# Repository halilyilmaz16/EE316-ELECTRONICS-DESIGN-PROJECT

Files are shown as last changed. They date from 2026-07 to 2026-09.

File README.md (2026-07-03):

# Capacitive Water Level Controller

An analog closed-loop water level control system designed and implemented
for the EE 316 Electronic Design Project at İzmir Institute of Technology.

The system detects liquid-level variations using a custom cylindrical
capacitive sensor. The sensor output is processed through phase detection,
filtering, amplification, error generation, and PWM stages. The resulting
PWM signal controls a submersible DC water pump through an L298N motor driver.

## Key Features

- Custom cylindrical capacitive water-level sensor
- TLC555-based oscillator
- XOR-based phase detection
- RC filtering and LM358 signal amplification
- Adjustable reference water level
- PWM-based pump speed control
- Motor overcurrent protection
- LTspice simulation and real-world circuit testing

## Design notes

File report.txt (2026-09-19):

Bilgi: İşlem sembolü 'C1:Capacitor_THT:C_Disc_D4.3mm_W1.9mm_P5.00mm'.
Bilgi: İşlem sembolü 'C2:Capacitor_THT:C_Disc_D5.0mm_W2.5mm_P5.00mm'.
Bilgi: İşlem sembolü 'C3:Capacitor_THT:CP_Radial_D5.0mm_P2.50mm'.
Bilgi: İşlem sembolü 'C4:Capacitor_THT:CP_Radial_D5.0mm_P2.50mm'.
Bilgi: İşlem sembolü 'C5:Capacitor_THT:CP_Radial_D5.0mm_P2.50mm'.
Bilgi: İşlem sembolü 'C6:Capacitor_THT:C_Disc_D4.3mm_W1.9mm_P5.00mm'.
Bilgi: İşlem sembolü 'C7:Capacitor_THT:C_Disc_D5.0mm_W2.5mm_P5.00mm'.
Bilgi: İşlem sembolü 'J1:Connector_PinSocket_2.54mm:PinSocket_1x02_P2.54mm_Vertical'.
Bilgi: İşlem sembolü 'J2:Connector_PinSocket_2.54mm:PinSocket_1x01_P2.54mm_Vertical'.
Bilgi: İşlem sembolü 'J3:Connector_PinSocket_2.54mm:PinSocket_1x02_P2.54mm_Vertical'.
Bilgi: İşlem sembolü 'R1:Resistor_THT:R_Axial_DIN0207_L6.3mm_D2.5mm_P7.62mm_Horizontal'.
Bilgi: İşlem sembolü 'R2:Resistor_THT:R_Axial_DIN0207_L6.3mm_D2.5mm_P7.62mm_Horizontal'.
Bilgi: İşlem sembolü 'R3:Resistor_THT:R_Axial_DIN0207_L6.3mm_D2.5mm_P7.62mm_Horizontal'.
Bilgi: İşlem sembolü 'R4:Resistor_THT:R_Axial_DIN0207_L6.3mm_D2.5mm_P7.62mm_Horizontal'.
Bilgi: İşlem sembolü 'R5:Resistor_THT:R_Axial_DIN0207_L6.3mm_D2.5mm_P7.62mm_Horizontal'.
Bilgi: İşlem sembolü 'R6:Resistor_THT:R_Axial_DIN0207_L6.3mm_D2.5mm_P7.62mm_Horizontal'.
Bilgi: İşlem sembolü 'R7:Resistor_THT:R_Axial_DIN0207_L6.3mm_D2.5mm_P7.62mm_Horizontal'.
Bilgi: İşlem sembolü 'R8:Resistor_THT:R_Axial_DIN0207_L6.3mm_D2.5mm_P7.62mm_Horizontal'.
Bilgi: İşlem sembolü 'R9:Resistor_THT:R_Axial_DIN0207_L6.3mm_D2.5mm_P7.62mm_Horizontal'.
Bilgi: İşlem sembolü 'R10:Resistor_THT:R_Axial_DIN0207_L6.3mm_D2.5mm_P7.62mm_Horizontal'.
Bilgi: İşlem sembolü 'R11:Resistor_THT:R_Axial_DIN0207_L6.3mm_D2.5mm_P7.62mm_Horizontal'.
Bilgi: İşlem sembolü 'R16:Resistor_THT:R_Axial_DIN0207_L6.3mm_D2.5mm_P7.62mm_Horizontal'.
Bilgi: İşlem sembolü 'R14:Resistor_THT:R_Axial_DIN0207_L6.3mm_D2.5mm_P7.62mm_Horizontal'.
Bilgi: İşlem sembolü 'R15:Resistor_THT:R_Axial_DIN0207_L6.3mm_D2.5mm_P7.62mm_Horizontal'.
Bilgi: İşlem sembolü 'R12:Resistor_THT:R_Axial_DIN0207_L6.3mm_D2.5mm_P7.62mm_Horizontal'.
Bilgi: İşlem sembolü 'R13:Resistor_THT:R_Axial_DIN0207_L6.3mm_D2.5mm_P7.62mm_Horizontal'.
Bilgi: İşlem sembolü 'RV1:Potentiometer_THT:Potentiometer_Piher_PC-16_Single_Vertical'.
Bilgi: İşlem sembolü 'U1:Package_DIP:DIP-8_W7.62mm'.
Bilgi: İşlem sembolü 'U2:Package_DIP:DIP-8_W7.62mm'.
Bilgi: İşlem sembolü 'U3:Package_DIP:DIP-14_W7.62mm'.
Bilgi: İşlem sembolü 'U4:Package_DIP:DIP-8_W7.62mm'.
Bilgi: İşlem sembolü 'U5:Package_DIP:DIP-14_W7.62mm'.
Bilgi: İşlem sembolü 'U6:Package_DIP:DIP-8_W7.62mm'.
R11 birim meta verileri güncellendi.
R11 iz düşümü 'Resistor_SMD:R_0603_1608Metric'den 'Resistor_THT:R_Axial_DIN0207_L6.3mm_D2.5mm_P7.62mm_Horizontal'e değiştirildi.
R11 alanı güncellendi.
Uyarı: U3 bileşeni 4 pedi için ağ bağlantısı bulunamadı (sembolde 4 pini yok).
Uyarı: U3 bileşeni 13 pedi için ağ bağlantısı bulunamadı (sembolde 13 pini yok).
Uyarı: U3 bileşeni 6 pedi için ağ bağlantısı bulunamadı (sembolde 6 pini yok).
Uyarı: U3 bileşeni 5 pedi için ağ bağlantısı bulunamadı (sembolde 5 pini yok).
Uyarı: U3 bileşeni 8 pedi için ağ bağlantısı bulunamadı (sembolde 8 pini yok).
Uyarı: U3 bileşeni 11 pedi için ağ bağlantısı bulunamadı (sembolde 11 pini yok).
Uyarı: U3 bileşeni 9 pedi için ağ bağlantısı bulunamadı (sembolde 9 pini yok).
Uyarı: U3 bileşeni 10 pedi için ağ bağlantısı bulunamadı (sembolde 10 pini yok).
Uyarı: U2 bileşeni 8 pedi için ağ bağlantısı bulunamadı (sembolde 8 pini yok).
Uyarı: U4 bileşeni 6 pedi için ağ bağlantısı bulunamadı (sembolde 6 pini yok).
Uyarı: U4 bileşeni 4 pedi için ağ bağlantısı bulunamadı (sembolde 4 pini yok).
Uyarı: U4 bileşeni 5 pedi için ağ bağlantısı bulunamadı (sembolde 5 pini yok).
Uyarı: U4 bileşeni 7 pedi için ağ bağlantısı bulunamadı (sembolde 7 pini yok).
Uyarı: U4 bileşeni 8 pedi için ağ bağlantısı bulunamadı (sembolde 8 pini yok).
Uyarı: U2 bileşeni 4 pedi için ağ bağlantısı bulunamadı (sembolde 4 pini yok).
Uyarı: U3 bileşeni 12 pedi için ağ bağlantısı bulunamadı (sembolde 12 pini yok).
Uyarı: U6 bileşeni 4 pedi için ağ bağlantısı bulunamadı (sembolde 4 pini yok).
Uyarı: U6 bileşeni 8 pedi için ağ bağlantısı bulunamadı (sembolde 8 pini yok).
Uyarı: U6 bileşeni 7 pedi için ağ bağlantısı bulunamadı (sembolde 7 pini yok).
Uyarı: U6 bileşeni 6 pedi için ağ bağlantısı bulunamadı (sembolde 6 pini yok).
Uyarı: U6 bileşeni 5 pedi için ağ bağlantısı bulunamadı (sembolde 5 pini yok).

Bilgi: Toplam uyarı: 21, hata: 0.

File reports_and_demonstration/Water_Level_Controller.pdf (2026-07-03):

## WATER LEVEL CONTROLLER

Electronic Design Project I

Hasan Veysel Tutar | Halil Yılmaz | Doruk Oğüt ¨

Department of Electrical and Electronics Engineering Izmir Institute of Technology

June 2026

Tutar, Yılmaz, Oğüt (IYTE) ¨ | Water Level Controller | June 2026 | 1 / 11

## Project Objective

Goal: Design an analog closed-loop system.

Maintain precise fluid levels inside the tank.

Prevent tank overflow and protect the pump from dry-run conditions.

Tutar, Yılmaz, Oğüt (IYTE) ¨ | Water Level Controller | June 2026 | 2 / 11

## Capacitive Probe Design

Cylindrical Capacitive Probe

Design Targets:

Target | Min. | Max. | Unit
Water level at capacitor | 5 | 15 | cm
Capacitance | 213 | 661 | pF

Governing Formula:

C =

2πϵ0
ln(b/a)

[Kw L1 + KaL2]

Kw ≈ 80 (Water)
Ka ≈ 1 (Air)

Result: Linear capacitance change relative to water height.

Tutar, Yılmaz, Oğüt (IYTE) ¨ | Water Level Controller | June 2026 | 3 / 11

## Clock Signal Generation

NE555 Timer
Configured in astable mode. Generates a continuous, stable square wave reference signal.

Design Formula:

f =

1.44
(RA + 2RB )C

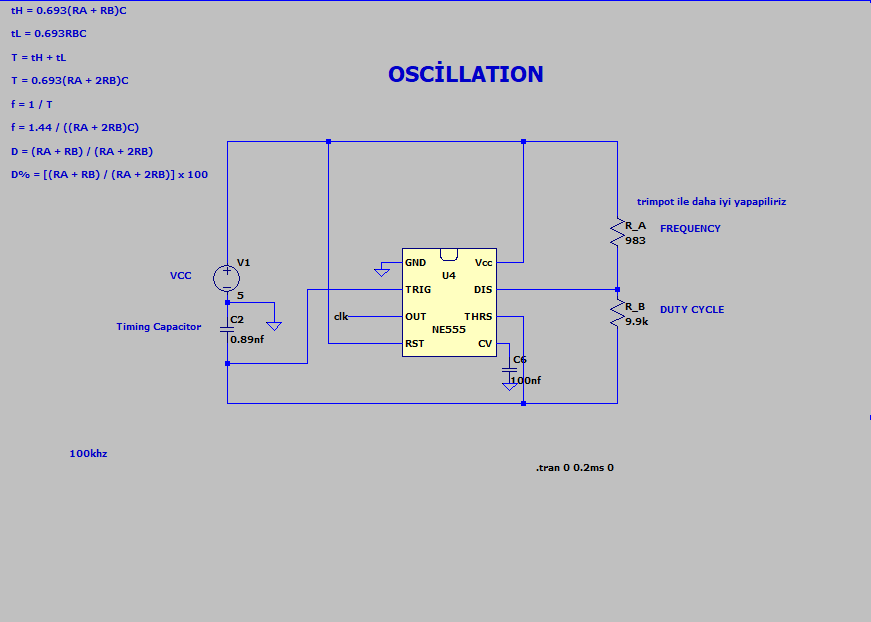
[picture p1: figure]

Figure: Clock Signal Generation Circuit

Tutar, Yılmaz, Oğüt (IYTE) ¨ | Water Level Controller | June 2026 | 4 / 11

## Phase Comparator & LP Filter

Phase Shift & XOR Output

74LS86 XOR: Compares the Reference Clock with the Phase-Shifted Signal from the capacitor. Pulse width is directly proportional to phase difference.

RC LP Filter: Converts the high-frequency switching PWM components into a stable DC voltage representing the water level.

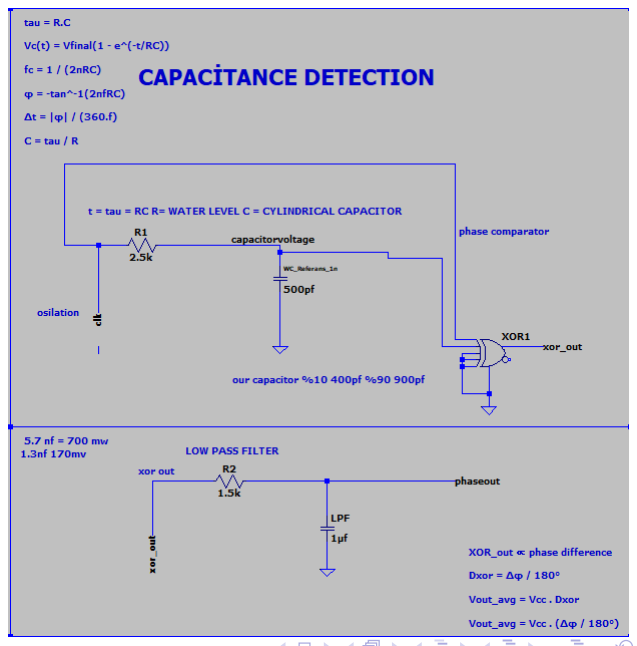
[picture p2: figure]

Figure: Phase Comparator Circuit Tutar, Yılmaz, Oğüt (IYTE) ¨ | Water Level Controller | June 2026 | 5 / 11

## Offset Amplifier

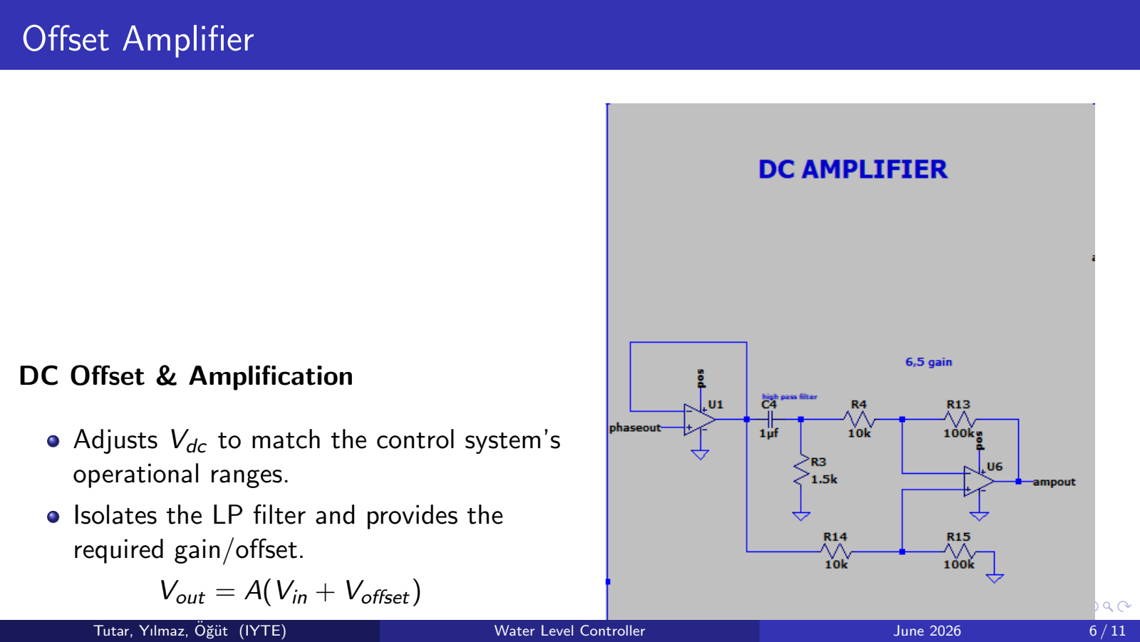
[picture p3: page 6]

DC Offset & Amplification

Adjusts Vdc to match the control system’s operational ranges.
Isolates the LP filter and provides the
required gain/offset.

Vout = A(Vin + Voffset)

Tutar, Yılmaz, Oğüt (IYTE) ¨ | Water Level Controller | June 2026 | 6 / 11

## Error Amplifier

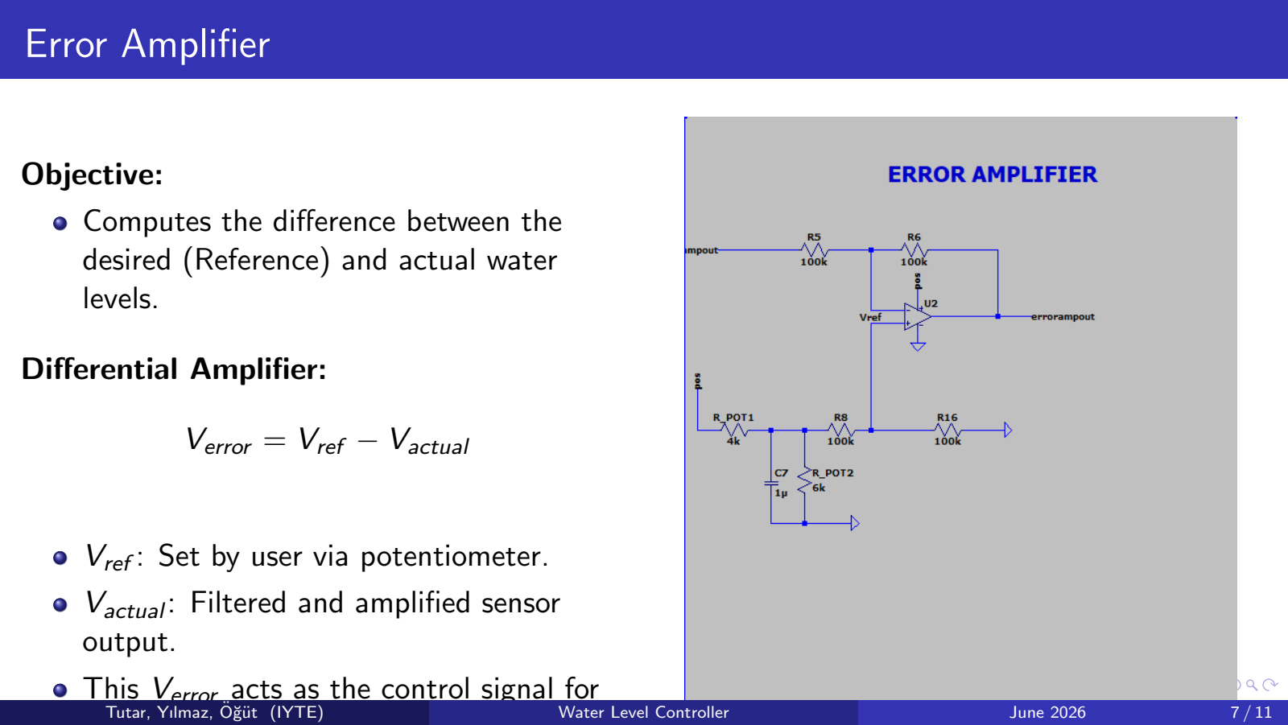
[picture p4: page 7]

Objective:

Computes the difference between the desired (Reference) and actual water levels.

Differential Amplifier:

Verror = Vref − Vactual

Vref : Set by user via potentiometer.

Vactual: Filtered and amplified sensor output.
This Verror acts as the control signal for
the PWM generation.
Tutar, Yılmaz, Oğüt (IYTE) ¨ | Water Level Controller | June 2026 | 7 / 11

## Reference Signal: Square & Triangular Wave

### 1. Square Wave Generator:

Created using 74LS74 D-type flip-flops.

Provides the base switching frequency

(fout = fclk /4).

### 2. Triangular Wave Generator:

RC filter network integrates the square
wave to produce a linear triangular carrier

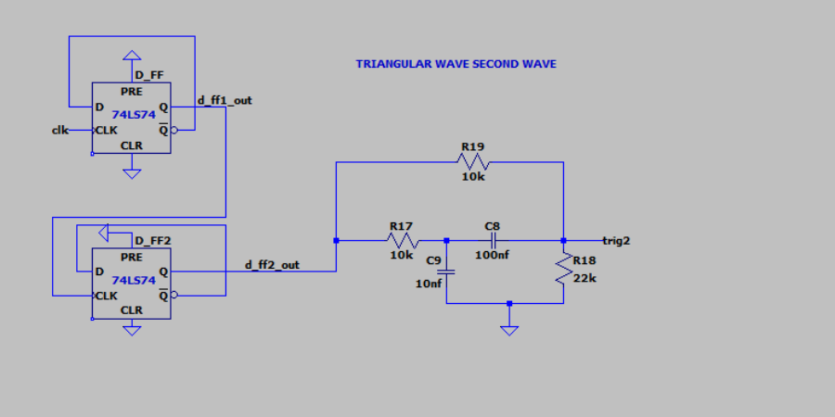
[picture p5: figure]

wave (Vtri). | Figure: Triangular Wave Generator
Tutar, Yılmaz, Oğüt (IYTE) ¨ | Water Level Controller | June 2026 | 8 / 11

## PWM Generator

Operation Principle:

Compares Verror and Vtri.

Logic:

If Verror > Vtri → HIGH

If Verror < Vtri → LOW

Result:
Duty cycle ∝ error.
High error (low water) = Fast pump speed.

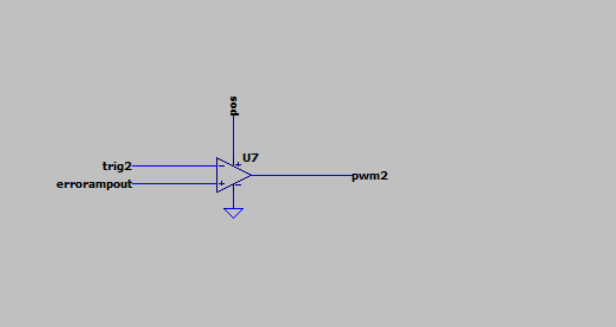
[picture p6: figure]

Figure: PWM Generator Circuit

Tutar, Yılmaz, Oğüt (IYTE) ¨ | Water Level Controller | June 2026 | 9 / 11

## Motor Driver Integration

L298N H-Bridge Driver

Drives the DC water pump using the generated PWM signal.
High-current capability suitable for inductive loads (up to 2A per channel).

Efficient power switching based on Duty Cycle, accurately controlling the pump flow rate.

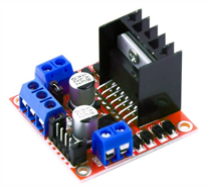
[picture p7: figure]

Figure: L298N Motor Driver Module

Tutar, Yılmaz, Oğüt (IYTE) ¨ | Water Level Controller | June 2026 | 10 / 11

# Thank You for Your Attention

EE 316 - Electronic Design Project I

Tutar, Yılmaz, Oğüt (IYTE) ¨ | Water Level Controller | June 2026 | 11 / 11

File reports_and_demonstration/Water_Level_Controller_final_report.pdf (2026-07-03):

İYTE - Department of Electrical and Electronics Engineering

EE 316 - Electronic Design Project, Sample Project Final Report | 1

## EE 316 - Electronic Design Project

## Project: P1

# Water Level Controller

## Final Project Report 25 June 2026

## Objective

To reduce water wastage and eliminate the need for human intervention when pumping water into tanks, it is important to design a simple control system that monitors water levels. This article presents the design and implementation of an automatic water level controller with a digital display. The circuit is low cost, easy to maintain, and operates on a replaceable battery. Our goal is to provide an efficient and effective solution for water level control in tanks using a simple circuit. Whether you are dealing with a domestic water tank or an industrial installation, a water level controller can make your life easier.

## Group Members

Common efforts:
Hasan Veysel Tutar: Capacitor design and manufacturing, real life circuit assembly and testing, and troubleshooting.
Halil Yılmaz: Simulations and circuit building assistance.
Doruk Öğüt: Simulations and circuit building assistance.

EE 316 - Electronic Design Project, Sample Project Final Report | 2

## Revision History

Week-5 (23.03.2026): We decided what to make the capacitor from.

Week-6 (30.03.2026): We tested our capacitor with the Signal Generator. We progressed as far as the DC signal section.

Week-7 (06.04.2026): We discussed how we could solve our oscillation problem with ICs. We decided on NE555 as the solution.

Week-8 (13.04.2026): We tested our Oscillation Circuit NE555 with electronic lab equipment [1].

Week-9 (20.04.2026): We tried to make progress by combining our oscillation circuit with a capacitor detection section.

Week-10 (27.04.2026): We have decided what we will use as an operational amplifier [6].

Week-11 (04.05.2026): According to our test results, the LM741 integrated circuit did not yield the same results as our simulations.

Week-12 (11.05.2026): Our datasheet research revealed that the LM358 integrated circuit is suitable for the remaining part of our circuit (Amplifier, PWM) [2].

Week-13 (18.05.2026): In the triangular wave section, we obtained a triangular wave by taking the main oscillation circuit, reducing its frequency to a quarter of its original value, and using filtering to account for possible offsets.

Week-14 (25.05.2026): Holiday week, The capacitor was broken, so we redesigned it.

Week-15 (01.06.2026): We completed all our circuits. We conducted troubleshooting for possible offsets.

Week-16 (08.06.2026): We completed all our circuits in the simulation. All the materials have been ordered.

Week-17 (15.06.2026): A demo video was filmed. A band member poured water on the circuit.

Week-18 (22.06.2026): Circuit Completed.

EE 316 - Electronic Design Project, Sample Project Final Report | 3

## 1.Introduction

The aim of this project is to develop an automated water level control system that uses capacitive sensing and feedback systems to reliably and effectively control water levels. The water level control system is designed to determine and manage the water level in a tank using capacitive sensors. When the water level drops below a certain level by the controller, the pump is triggered. When the water level rises above a certain limit, the pump shuts off.

Capacitive sensors, signal processing circuits, and a driver module used to operate a PWM-controlled motor are the system's core components. The dielectric properties of water allow the sensor to detect changes in water level. Resistors and capacitors, including logic gates and analog filters, pass the output from the sensors through various stages.

Another essential part of the system is a feedback loop controlled by an error amplifier. In this loop, the water level and the reference value are continuously compared. The amplifier adjusts control indicators that amplify any discrepancies between the reference value and the water level, thus maintaining the water at the correct level within the system [6].

The output of the error amplifier is used to generate the PWM signal [7]. The capacitive sensor detects the water levels, and the duty cycle of the PWM signal changes the motor operation. When the water level in the tank is below the desired level or completely empty, the motor operates at its maximum duty cycle [10]. As the water level in the tank rises, the duty cycle decreases and the motor switches off. The system also ensures smooth operation of the motor with a current-protected motor driver circuit.

We must overcome three major design challenges by making a water level controller:

Custom Capacitive Sensor Fabrication: Precise level detection necessitates exceptional geometric accuracy. To reduce expenses and prevent measurement inaccuracies associated with the "kettle effect," we utilized SolidWorks and 3D printing to fabricate tailored frames [9]. A continuous, single component aluminum surface was employed to enhance sensitivity, while premium electrical tape acted as a dielectric barrier to inhibit leakage currents and thermal fluctuations.

Signal Conversion through Oscillation: It is necessary to transform the sensor's changing capacitance into a digital signal. Capacitance variations are converted into a frequency modulated square wave using an astable mode NE555 timer [1]. The difficulty is choosing exact R1 and R2 values to retain high resolution while keeping the output frequency within the microcontroller's

Parasitic Voltage Leakage: A 500 mV leakage was detected at the XOR output during measurement, causing noise and reducing signal reliability. This became one of the project’s challenges and required improved grounding, insulation, and filtering.

EE 316 - Electronic Design Project, Sample Project Final Report | 4

## 1.1. Capacitive Water Level Sensors

Our system employs cylindrical capacitive sensors to detect variations in capacitance between two aluminum strips and a plastic tube situated within a tank filled with water. Fluctuations in the water level led the sensors to register changes in capacitance between the electrodes. The higher dielectric constant of water in comparison to air results in an increase in capacitance as the water level rises. We assessed and calculated the capacitance of the capacitor in air and observed how it varied at different water levels. Preliminary experiments indicated that the presence of water on the aluminum surface influenced the conductivity of the capacitor plates. Consequently, we applied a thin layer of plastic wrapping around the capacitive sensors to enhance their sensitivity. This adjustment enabled us to effectively track water levels. We employed the NE555 timer integrated circuit to produce a clock signal with the specified frequency and duty cycle values within the 0 − 5V range.

## 1.2. Signal Conditioning and DC Conversion

The capacitor's output was converted to direct current (DC) to enable the DC motor to operate effectively [5]. Our clock signal was subsequently used to feed the circuit after it was constructed, functioning as a phase comparison device. The circuit measured the phase difference between our clock signal and the capacitor output, generating a corresponding signal. This was achieved using a comparator comprising two XOR gates; the first digitized our system, while the second compared the capacitor output with the clock signal. The comparator's output was then passed through a low pass filter to produce a DC voltage signal. Prior to utilization, it was necessary to amplify the DC output, as the signal amplitude was initially too low, which risked amplification errors [8].

## 1.3. Error Amplification

We see that the error amplifier is a circuit that compares the difference between the reference water level and the actual water level. This acts as a feedback loop and keeps the system within its most effective range. When there is a difference between the reference level and the actual level, it continuously monitors and amplifies this difference through the error amplifier [7]. Initially, in the simulation, the supply voltages for the amplifier were set to 5V and GND, and Vrefwas varied between 0V and 4V. (Note that the maximum amplified DC signal level is 4V. In the experimental setup, a potentiometer is used to adjust the reference voltage. The water level in the bottle is divided into intervals, and the adjustment of the DC signal voltage values is matched to this interval. In this arrangement, the potentiometer sets a reference level voltage, and when the target water level is reached, the error amplifier compares this reference voltage to an actual voltage signal indicating how much water is in the container. Therefore, the motors only pump water when the water level is below the maximum level [6].

EE 316 - Electronic Design Project, Sample Project Final Report | 5

## 1.4 PWM Generation

The square wave generated by the NE555 timer first passes through an RC filter circuit to create a delayed version of the original signal. This delayed signal is then converted into a digital signal by using a ground reference XOR gate. After that, another XOR gate compares the original NE555 timer output with the digitized delayed signal. As a result of this comparison, a difference signal is produced at a very small millivolt level. Since this signal is too weak for direct use, it is amplified by a non inverting amplifier stage [6]. After amplification, the signal is applied to a differential amplifier, also called an error amplifier, together with a previously adjusted reference voltage to generate an error signal [7]. This error signal is then sent to the PWM generation stage, where it is compared with a triangular waveform to produce the PWM output. The duty cycle of the PWM signal changes continuously according to the water level, which allows accurate control of both the motor speed and the water flow [10].

## 1.5 Motor Driver Integration and Protection Circuit

Using PWM to drive the motor via L298 motor driver IC [4]. This integrated circuits design means it can switch effectively and operate safely with the DC motor [5]. The motor speed is directly controlled by the PWM duty cycle, which can be accurately regulated for water pump operation. The system can autorotate motor speed changes and keep water balance by changing the duty cycle according to the water level. This method made the operational safety and functionality of the motor even better.

## 1.6 Motor and Pump Control

The submersible pump can connect to a motor that runs based on the PWM controlled signal [10]. When the water comes to a maximum, the system reduces duties which slow down or stop pump action. The duty cycle increases when the water level drops below the minimum value, and pump runs to fill up the tank. Also, the present protection circuit is integrated to safeguard likely damage from carrying out such postures through the mode of motor overcurrent circumstances. Move on with the project, at this stage these circuit parts will be implemented over to a breadboard and at each stage signal integrity will be checked and finally check the full system operation under various water level conditions.

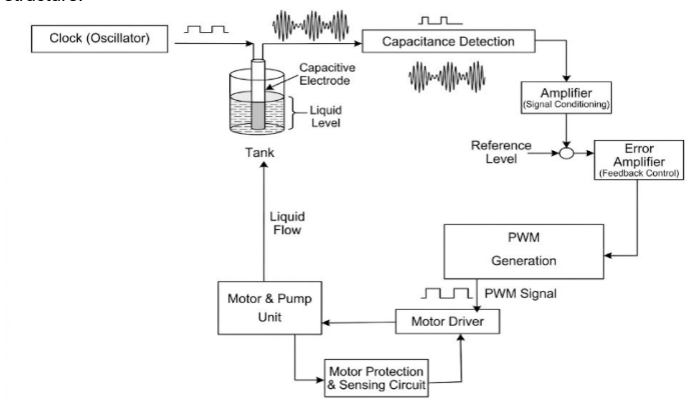
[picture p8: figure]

EE 316 - Electronic Design Project, Sample Project Final Report | 6

## 2. Technical Description

In order to accurately and continuously monitor the liquid level in the tank, we built this system with a closed-loop control structure. In our design, we sensed the liquid level by placing a capacitive electrode inside the tank. We were able to measure the capacitance change that happens when the liquid level varies by applying a high frequency signal produced by an oscillator from a constant DC source to this electrode. We converted this change obtained in the capacitive sensing block into an electrical signal and then processed it in the amplifier stage to bring it to a suitable level for control. We then compared this signal with a defined reference level in the error amplifier block to obtain the instantaneous error information of the system [7]. By transferring the generated error signal to the PWM generation block, we aimed to create the control signal to be used in the next stage of the system. The next goal of our design is to apply the generated PWM signal to a motor driver circuit to control the pump motor and thus automatically maintain the liquid level in the tank at the desired value. Accordingly, the motor driver, pump, and protection circuit blocks are planned for the later development stages of the system. With this approach, our primary goal is to establish the sensing and control infrastructure, and in the next stage, to transform the system into a fully closed-loop liquid level control structure.

Figure 1. Block Diagram of the Water Level Control System
The system begins by using a clock to create a square wave, which is subsequently transmitted to a capacitor's electrode. In the capacitance detecting part, we also want to produce a DC signal, which requires several intricate procedures.

First, we used a NE555 timer in astable mode to transform the steady DC supply voltage into a steady clock signal [1]. The handcrafted capacitive sensor, whose output changes with capacitance, was then subjected to this clock signal. A phase comparator was used to compare the reference clock and sensor output, and the resulting signal was transformed into PWM for the subsequent motor control stage.

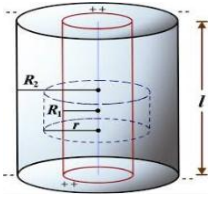
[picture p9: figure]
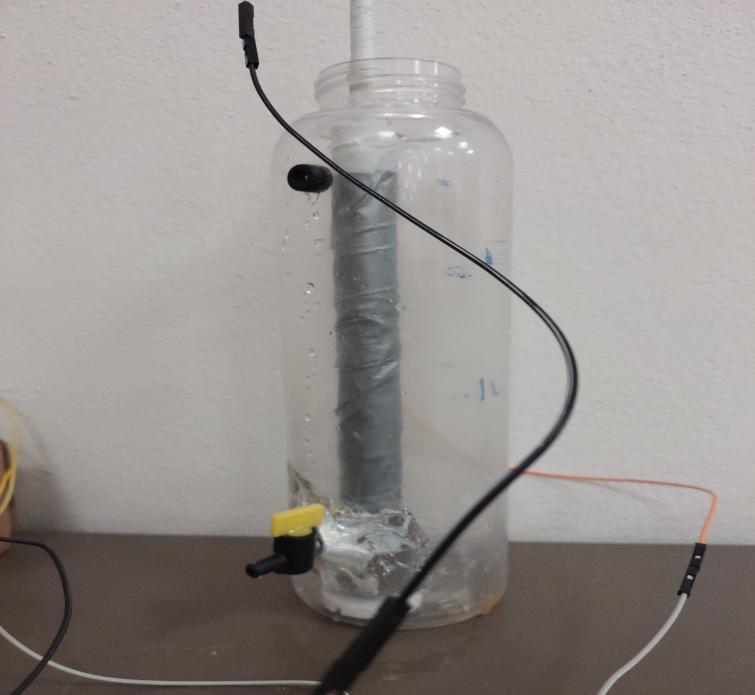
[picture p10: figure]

EE 316 - Electronic Design Project, Sample Project Final Report | 7

## 2.1. Capacitor Design

When designing our capacitor, we experimented with a variety of methods. In the end, we decided to create it using a 3D printer. The height and outside diameter of our capacitor were measured theoretically and determined to be 25 cm and 24.8 mm, respectively.

It was found that the cylinder within the capacitor was 28 cm tall. Additionally, the capacitor's inner and outer shell radii were found to be 4.2 mm and 9 cm, respectively, as seen in Figure 2 below.

Figure 2. Diagram of cylindrical capacitor

The capacitive sensor was built using aluminum tape on the external surfaces of the inner and outer cylindrical shells that formed the electrode structure of the sensor. This arrangement provides a measurable capacitance between the two conductive layers that varies according to the surrounding dielectric medium and enables liquid level detection as shown in Figure 3 below.

Figure 3.Picture of the Capacitor

EE 316 - Electronic Design Project, Sample Project Final Report | 8

According to our research, the formula for the capacitance of a cylindrical capacitor is given

(1)

C is the capacitance of the cylinder, a is the inner radius of the cylinder, L is
the length of the cylinder, b is the outer radius of the cylinder, | is the permittivity of
free space, and | is the permittivity of medium.
= | (2)
= | (3)

Then the total capacitance is:

| (4)
= | (5)

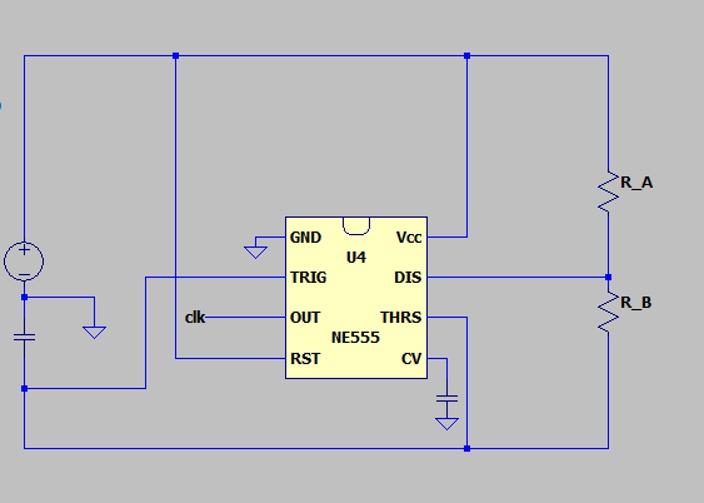
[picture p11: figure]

EE 316 - Electronic Design Project, Sample Project Final Report | 9

## 2.2 Oscillation Generation

Based on our preliminary research and design requirements, we selected the TLC555 timer to generate the excitation signal for the sensing stage. Due to its simple implementation, stable operation, and ability to produce a continuous square wave without external triggering, the TLC555 was chosen as the oscillator source [1]. Configured in astable mode, it generates a stable periodic signal that is used as the reference excitation input for the capacitive sensing circuit .

TLC 555 Astable Multivibrator

The TLC555 astable multivibrator circuit shown in Figure 4 generates a clock
signal, | ,which is a 35 kHz square wave oscillating between | and | ,
with approximately a | duty cycle. This clock signal provides a stable timing
reference essential for DC signal generation in our design [1].

Figure 4.TLC555 astable oscillator generates the reference square-wave signal

The Frequency is calculated with this formula:

(6)
And the duty cycle is calculated with:

(7)

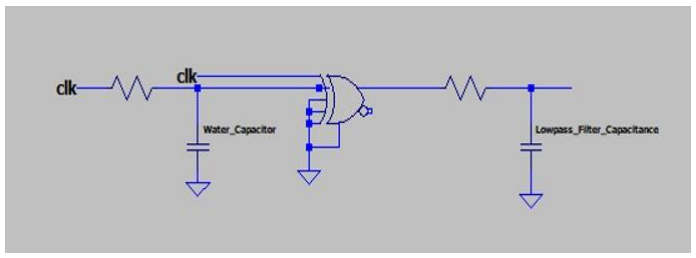
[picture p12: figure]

EE 316 - Electronic Design Project, Sample Project Final Report | 10

## 2.3 Capacitance Detection

At this point, we employed a straightforward RC network to monitor the charge discharge behavior of our capacitive sensor using the produced square wave signal. Based on the capacitor's charging and discharging properties, a phase-shifted waveform was produced when it reacted to the excitation signal. In order to stabilize the waveform and retrieve its phase-dependent behavior, this signal was then processed utilizing XOR-based phase comparison stages.

Figure 5.Circuit Diagram of Capacitance Detection
Delayed Signal Generation

Based on our preliminary research, we found that the simplest way to observe the capacitance variation of our handmade sensor was to examine its charge discharge behavior in a basic structure. By applying the generated square wave signal to the sensor, we obtained a delayed output due to the capacitor’s charging and discharging response. This phase shifted waveform allowed us to observe the capacitance effect directly in the time domain

The delay is determined by the time constant,

and the delayed output is described by

Signal Digitalization and Convert DC

Based on our analysis, the delayed analog signal needed to be converted into a more stable and measurable form for evaluation. To achieve this, we compared the delayed capacitor response with the reference clock signal using XOR-based phase comparison. Since the XOR gate (74LS86) produces HIGH output only when its inputs differ, the phase difference between the delayed signal and the reference signal was translated into a pulse-width-varying digital waveform [2].

The digital output was processed to obtain a stable, DC equivalent signal proportional to the detected phase shift. By converting the phase-dependent waveform into a DC level, a more stable representation of the capacitance variation was achieved. This enabled the sensor response to be observed as a measurable voltage level, thereby simplifying the evaluation of capacitance dependent behavior.

EE 316 - Electronic Design Project, Sample Project Final Report | 11

Filtering

After the XOR stage, the output signal contains high-frequency switching components and must be filtered to obtain a stable DC level. For this purpose, an low-pass filter is used to suppress the high-frequency ripple while preserving the average value of the signal. This allows the phase-dependent digital waveform to be converted into a smoother and more stable DC output.

The cutoff frequency of the filter is determined by:
=

This relation was used to select the filter parameters and evaluate the response of the filtering stage.

Capacitance Detector Design Targets
Description of design target | Min. | Max. | Unit
Delayed signal output voltage | 0 | 4.96
DC signal output voltage | 0 | 578
Filtering Frequency | 10 | 23
Capacitance Value | 1.5 | 5.15

Table 1. Capacitance Detection Design

## 2.4 Amplifier

Following the theory learned from the principles of analog amplifiers in Circuit Analysis I, an operational amplifier was employed to boost the voltage output after filtration.

A high pass filter was designed to limit any noise in low frequencies prior to amplifying the input signal.

Because the output voltage from the capacitance detection stage was too low for comparison purposes, a non-inverting amplifier was chosen to boost the output signal voltage while keeping its polarity intact.

The output voltage is expressed by the equation below:

Using the resistor values chosen above, the gain was controlled to achieve the desired output voltage. The circuit design is depicted in Figure 6. The output voltages are provided in the table below.

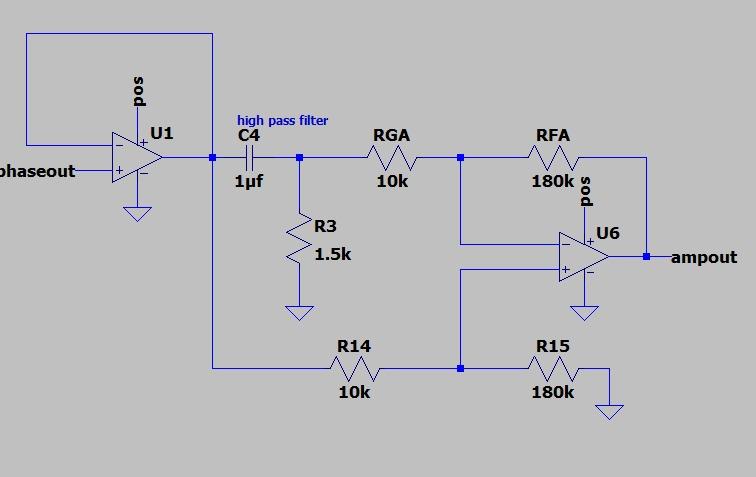
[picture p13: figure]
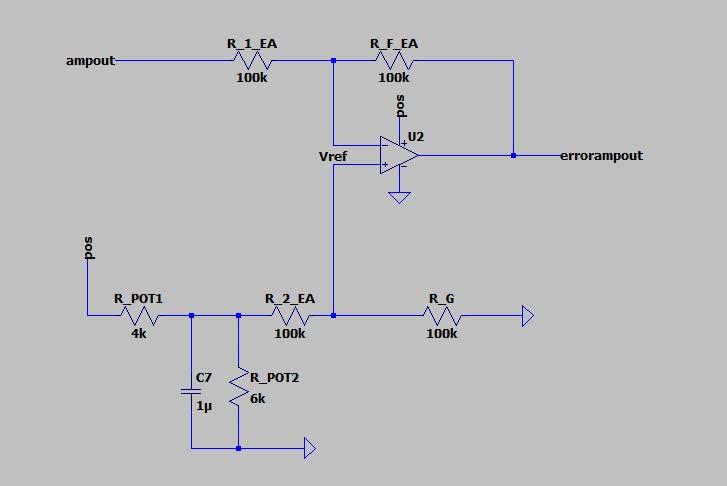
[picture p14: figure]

EE 316 - Electronic Design Project, Sample Project Final Report | 12

Figure 6.Circuit diagram of Amplifier
Amplifier Design Targets
Description of design target | Min. | Max. | Unit.
DC Voltage | 170 | 700 | mV
Output voltage for non-inverting amplifier | 3 | 4.2
Gain | 7.2 | 56.44 | -

Table 2. Amplifier design targets and parameters

## 2.5 Error Generation and Level Adjustment

Here, the error amplifier is employed to compare the amplified sensor output with a variable reference voltage. This reference voltage is connected to the non-inverting terminal of the operational amplifier via the voltage divider formed using a potentiometer, whereas the amplified DC signal is fed to the inverting terminal via resistor R5. The potentiometer can be used to set the required level of water manually. Thus, the output of the error amplifier circuit is the difference between the sensed and reference levels of water.

Figure 7. Error Amplifier

EE 316 - Electronic Design Project, Sample Project Final Report | 13

Error Amplifier Design Targets
Description of design target | Min. | Max. | Unit
DC voltage (from the amplifier) | 1 | 5.1
Output Voltage | 0.234 | 4
Referance Voltage | 1.03 | 4.5

Table 3. Design Targets for the Error Amplifier

The equation for output voltage from the error amplifier will be:

Where in the circuit | So the equation will become,

(12)
Finally, the output equation can be simplified as:

(13)

It means the error amplifier provides its output according to the difference between selected water level reference and the sensor voltage

## 2.6 Triangular Wave and PWM Generator

Two cascaded 74LS74 D-type flip-flops and an RC wave-shaping network were used in the revised design to create the triangular reference waveform. After two stages, the output frequency is as follows because each flip-flop divides the input clock frequency by two:

(14)

After that, the divided square-wave signal was fed into a circuit with parallel high-pass and low-pass filter branches and a DC route. The square wave was transformed into a roughly triangular waveform by the combined response of these
branches. | Each | RC | filter's | cutoff | frequency | is | determined | by
| | | | | | | (15)

The error amplifier output and the triangular reference waveform were compared
during the PWM generation stage. When | exceeds | , the PWM output

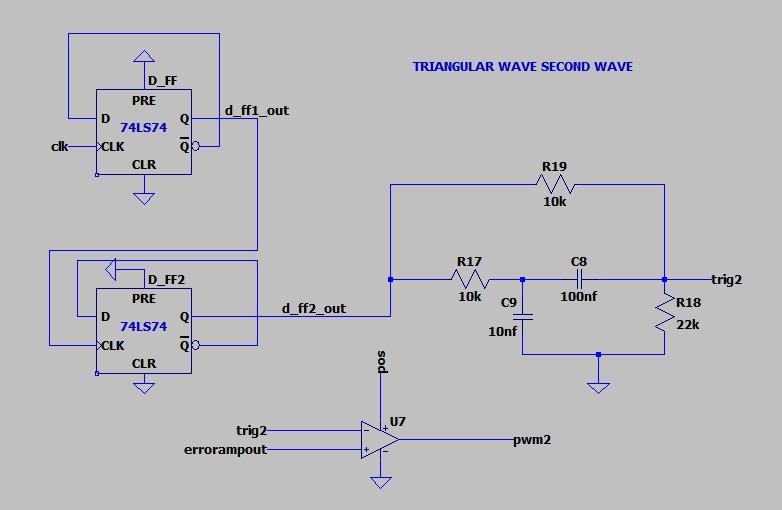
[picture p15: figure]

EE 316 - Electronic Design Project, Sample Project Final Report | 14
is HIGH; when | falls below | , it is LOW. As a result, while the frequency
of the PWM signal stays constant, changes in the error amplifier output alter its duty cycle.

The figure and tables below show the triangular-wave generation circuit, PWM output, and related measurement results.

Figure 8. Triangle Signal Generator and PWM

Clock Signal for triangular wave Design Targets
Description of design target | Min. | Max. | Unit
Input voltage | 4.95 | 5.05 | V
Output low voltage | 0 | 28.26 | mV
Output high voltage | 4.95 | 4.99 | V
Output duty cycle | 84 | 88 | %
Output frequency | 9 | 9.98 | kHz

Table 4.Design targets for the PWM triangular wave

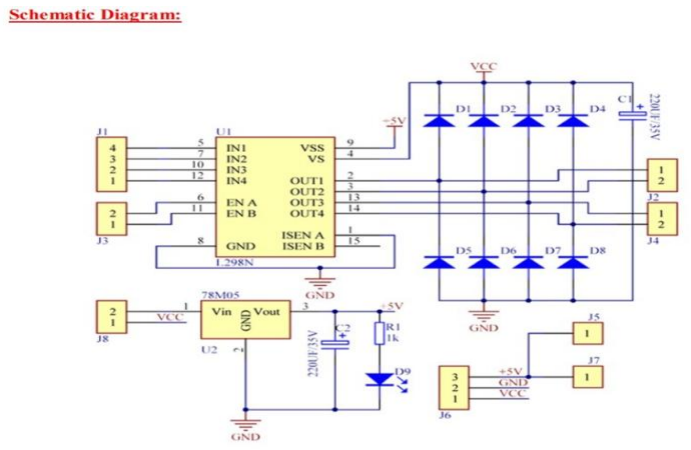
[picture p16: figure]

EE 316 - Electronic Design Project, Sample Project Final Report | 15

## 2.7 Motor Drive

In this case, the L298 DC and stepper motor driver is employed to operate the motor. The L298 is a dual H-Bridge motor driver that is widely used for driving DC and stepper motors. In this setup, the L298 driver is used to regulate the speed of the DC motor using the output PWM signals.

Generally, the L298N driver can support relatively high current and voltages of up to 2A per channel and 46V. Besides, the L298N comes with protection circuits such as over-current and thermal shutdown which makes the circuit operation safe. The chosen DC motor runs at either 12V/3A or 6.5V/2A. The voltages and currents are within the range of the chosen motor driver module [4].

Figure 9.The pinout configuration of L298N Module

The procedure starts with generating a square wave clock signal. This signal is provided to the capacitive electrode, and the capacitance value is altered in response to the level of water in the tank. Besides, the whole circuit should generate a DC signal after passing through several processing operations in the capacitive detection circuit.

At first, the clock signal is generated by the NE555 timer in astable mode. The clock signal then goes through the handmade capacitive sensor, and the output from it depends on the capacitance changes. Next, the output of the clock signal and the output of the sensor are connected to the phase comparator. The output from it becomes the PWM signal, thus allowing varying the duty cycle.

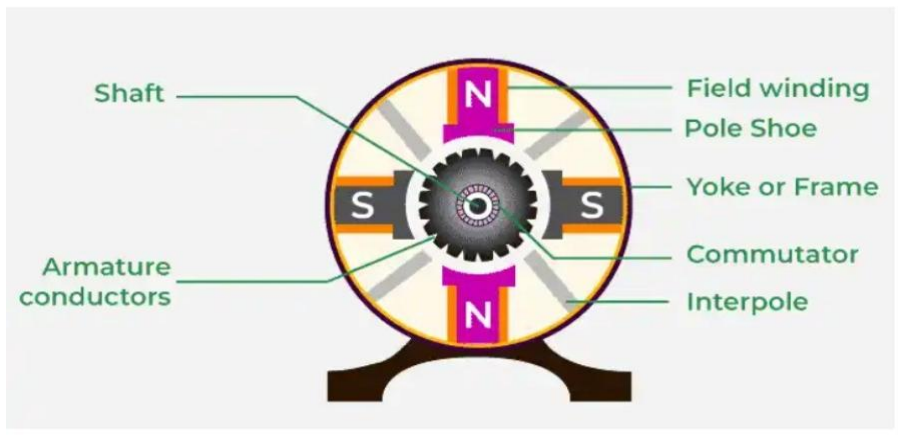
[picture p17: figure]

EE 316 - Electronic Design Project, Sample Project Final Report | 16

## 2.8 DC Motor

A 12 V DC brushless submersible motor is chosen in this work to pump the water and to control the level of water in the tank. DC motors run on DC power and can be energized by a DC voltage source. The chosen motor was tested in the lab and runs properly with 12 V/3 A or 6.5 V/2 A.

The structure of a basic 12 V DC motor is illustrated in figure 9. The basic elements of the motor are rotor with permanent magnets and stator with electromagnetic windings.

Figure 10. DC motor mechanics scheme
DC motors are perfect for tasks requiring adjustable speed and torque characteristics. In this project, the motor speed is controlled via the change in PWM duty cycle. Thus, the water flow can be regulated depending on the level of water in the tank [6]

EE 316 - Electronic Design Project, Sample Project Final Report | 17

## 2.9 Motor Protection Circuit

The ACS712 is a Hall effect current sensor that generates output voltage directly proportional to the current passed through it. In this case, the ACS712 current sensor measures the current consumed by the DC motor. The output voltage of the current sensor is supplied to the inverting input terminal of the LM393P comparator whereas the non-inverting input terminal receives the reference voltage set as the ACS712 output voltage for the current of 2 A.

The comparator compares the motor current with the threshold level. The output of the comparator will be high when the measured current is less than 2 A. The output of the comparator is used to drive the MOSFET gate voltage close to 5V in this case. The motor operation will be enabled by turning on the MOSFET. However, when the current is greater than 2 A, the output of the comparator will go low disabling the enable signal of the motor driver circuit.

Moreover, a Schmitt Trigger stage is used in order to achieve cleaner switching performance. Without it, there may be an unstable output or output that remains in a state somewhere in between HIGH and LOW state of the comparator output depending on how much the input voltages differ. These uncertain states of output may not be enough for a full activation of MOSFET. This situation is avoided by using the Schmitt Trigger since its output will definitely be in either HIGH or LOW state only.

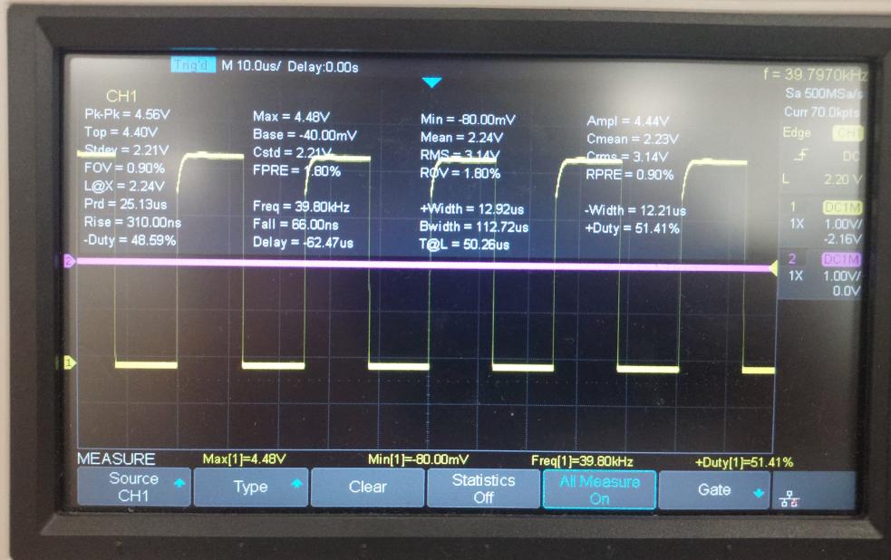
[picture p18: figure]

EE 316 - Electronic Design Project, Sample Project Final Report | 18

## 3 Test Results

## 3.1 Oscillation Generation

The measurements corresponding to the oscillation signal generated by 555 timer circuit are given in the figure and following table.

Figure 11. The output of NE555 Timer Circuit

Oscillation Signal Design Results
Design Targets | Results | Unit
Input voltage | 5.1 | V
Output low voltage | -80 | mV
Output high voltage | 4.48 | V
Output duty cycle | 48.59 | %
Output frequency | 39.80 | kHz

Table 5. Oscillation Circuit Result
The simulation yielded a value close to what was tested. However, the actual result is always different.

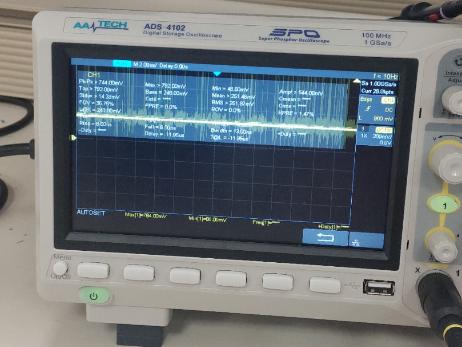
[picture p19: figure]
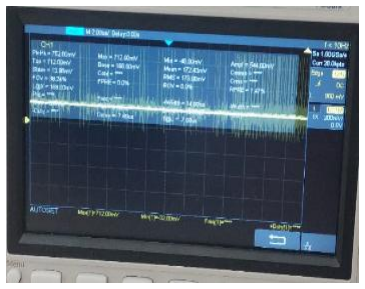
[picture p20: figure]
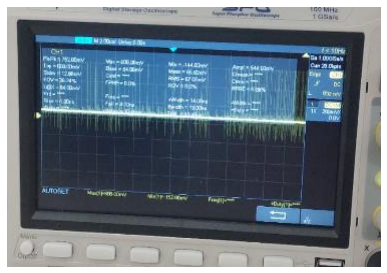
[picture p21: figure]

EE 316 - Electronic Design Project, Sample Project Final Report | 19

## 3.2 Capacitance Detection

The minimum capacitor values and low-pass filter results obtained are shown in the table and photographs.

Capacitance Detector Design Results
Design Targets | Min. | Max. | Unit
Delayed signal output voltage | -60 | 3.6 | V
DC signal output voltage(LPF) | 60 | 250 | mV
Filtering Frequency (Capacitor) | 35.4 | 38.9 | kHz
Capacitance Value | 1.1 | 5.4 | nF
Filtering Frequency (for DC signal) | 35 | 46 | Hz

Table 6. Capacitande Detection Part Results

Now, the low-pass outputs are 10%, 50%, and 90%, respectively.

- For %10
- For %50
- For %90

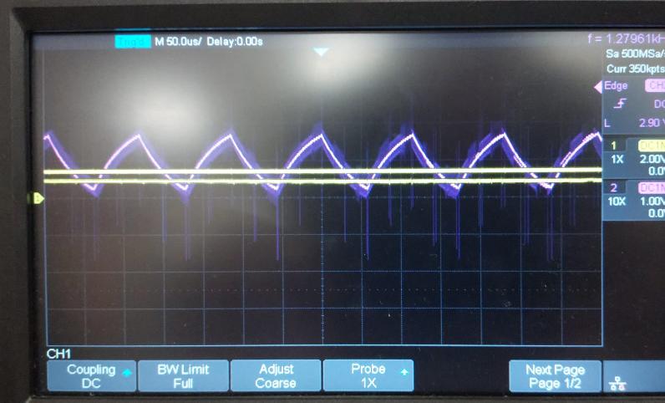
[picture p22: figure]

EE 316 - Electronic Design Project, Sample Project Final Report | 20

## 3.3 DC Offset Amplifier and Level-Adjustment

Our dc amplifier and error generation results are shown below. First amplifier table,

DC Offset Amplifier Design Results
Design targets | Min. | Max. | Unit
DC voltage | 60 | 250 | mV
Output voltage for non-inverting amplifier | 0.987 | 4.347 | V
DC Signal gain | 18 | 30 | -

Table 7. Amplifier Circuit Results

We determined that the LM741 was not suitable for our circuit. We had initially considered using the LM741 when designing the circuit. However, our tests revealed that LM358 was a more suitable alternative [2].

Our error amplifier figure and table are now below.

Figure 12.Error signal is yellow

Error Amplifier Design Results
Design targets | Min. | Max. | Unit
DC voltage (from the non-inverting amplifier) | 0.905 | 4.352 | V
Reference voltage | 1.02 | 4.6 | V
Output voltage | 0.045 | 3.57 | V
Referance Resistor | 1.05 | 9.10 | kΩ

Table 8. Error Amplifier Results

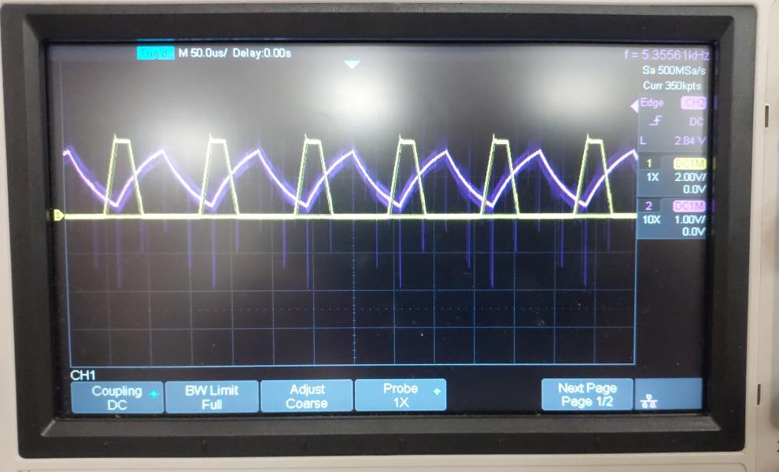
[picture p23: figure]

EE 316 - Electronic Design Project, Sample Project Final Report | 21

## 3.4 Triangular Wave and PWM Generation

We reduced the frequency of our signal from the main oscillator using a 74ls74 in real-world scenarios. The test results are shown in the figure and table below.

Figure 13 Triangular wave and PWM Signals

Triangular wave and PWM Design Results
Design targets | Measured | Unit
Triangular low voltage | 104.5 | mV
Triangular high voltage | 3.53 | V
Triangular duty cycle | 92.6 | %
Triangular wave frequency | 9.08 | kHz
Output high voltage (PWM) | 4.56 | V

Table 9. Triangular wave and PWM Results
When the error signal voltage is higher than triangular voltage, the PWM signal becomes HIGH. In real life, some noise may have occurred. It had no effect; better conditions can be created by moving the circuit in the air or from side to side.

EE 316 - Electronic Design Project, Sample Project Final Report | 22

## 4. Measurement and Simulation Methods

Figure and Description | Measured Quantity | Equipment / Tool | Explanation / Method
Figure-3: Picture of capacitor | Capacitance(nf) | Multimeter | We measured it with a multimeter.
Figure -14:TLC555 astable oscillator generates the reference square-wave signal | Clock Frequency(khz), Duty Cycle(%) | Ltspice | A circuit was created and measurements were taken using Ltspice.
Figure- 15:Triangle Signal Generator and PWM | Triangular Peak Voltage (V) | Ltspice | It was tested and found to give 5V at points where the error voltage was greater than the triangle wave.
Figure-16:The output of NE555 Timer Circuit | Frequency (kHz) | Digital Oscilloscope | The oscillation frequency measured as 39.80 kHz.
Capacitance Detection Figures | Switching Voltage mV | Digital Oscilloscope | 60mV was measured at 10% and 250mV at 90%.
Figure 17 Triangular wave and PWM Signals | PWM voltage (V) | Digital Oscilloscope | At points where the error signal was high, the PWM voltage was measured at 4.56 V.

EE 316 - Electronic Design Project, Sample Project Final Report | 23

## 5. Conclusion

Automatic water level control system was designed and implemented by our team. In this design, the variations in water level are converted to capacitance variations. The capacitance variations are further processed using phase comparison and filtering techniques to obtain a DC signal. The signal obtained is amplified using an error amplifier and the output is compared with triangular wave form to obtain a PWM signal. The PWM signal controls the speed of submersible DC motor using motor driver circuit.

Improved design of capacitive sensor has been done for better measurements and sensitivity. The capacitive sensors having cylindrical shapes made with aluminum tape electrodes have been employed and the electrodes have been insulated with insulation layer to avoid direct contact of water.

The feedback control scheme of the system is mostly done with the help of the error amplifier output. The error voltage changes depending on the difference between the actual water level and the reference level. This helps adjust the PWM duty cycle which in turn helps change the speed of the motor depending on the water level and keep the water level at the required value. Moreover, an overcurrent protection circuit was added with the help of a current sensor and comparator.

During the course of the project, both simulations and practical circuit tests were conducted. Some problems arose during the project such as problems with the conductivity of the capacitive sensor and the calibration of the error amplifier circuitry. The problem with the conductivity of the capacitive sensor was solved through the insulation of the capacitor.

In summary, through this project, our group gained firsthand experience in analog electronics, feedback systems, PWM creation, sensor development, and overcurrent protection circuitry. The resulting system includes numerous vital components, such as the homemade cylindrical capacitor, clock signal generator, RC filters, error amplifier, PWM generator, motor controller, and overcurrent protection circuit. All these components together comprise an automatic water level control system [10].

EE 316 - Electronic Design Project, Sample Project Final Report | 24

## 6. Component List and Cost

Component description | Part Number | Manufacturer | Supplier | Cost (TRY)
Timer/Clock | TLC 555 | Texas Instruments | cakirelektronik.com | 10.6
Operational amplifier | LM358P | Texas Instruments | cakirelektronik.com | 7.96
Logic gate (XOR gate) | 74LS86 | STM Philips | cakirelektronik.com | 11.89
DC Motor Driver Module | L298N | GlintDeer | cakirelektronik.com | 104.2
D Flip Flop | 74LS74 | Texas Instruments | cakirelektronik.com | 12.5

The total cost of the necessary hardware parts needed in this project is estimated at 200 TRY. As this system involves the use of mostly inexpensive electronic parts like op-amp, logic gate, timer IC, and motor driver module, therefore it is economical. Almost all of the parts can be purchased locally from the websites of electronics suppliers like Direnc.net and Robotistan. The costliest part in the given list is the L298 motor driver module which is inexpensive enough to drive the DC motor in this project. Hence, the water level control system designed is low-cost and feasible [2].

EE 316 - Electronic Design Project, Sample Project Final Report | 25

## 7. Project Management

Project Steps | Project Member#1 (Hasan Veysel TUTAR) | Project Member#2 (Halil Yılmaz) | Project Member#3 (Doruk Öğüt)
555 Timer design and simulation | X | X | X
555Timer experiment setup and test | X X
Capacitor Design | X | X
Capacitor Setup and test | X
PWM design and Simulations | | X X
PWM Setup and Test | X
Low pass design and simulations | | X X
Low Pass setup and Test | X
Error Amplifier Design and Simulations | | X X
Error Amplifier Setup and Test | X X
Triangular Wave Design and Simulations | | X X
Triangular Wave Setup and Test | X
DC Amplifier design and Simulations | X | X | X
DC Amplifier Setup and Test | X
Lab Attendance | XX | X | X
Parts Procurement | X | X | X
Report Writing | X | X | X
Motor Driver Setup and Test | X X
Laboratory Support | X | X | XX

EE 316 - Electronic Design Project, Sample Project Final Report | 26

## References

[1] Texas Instruments, TLC555 LinCMOS Timer Datasheet, Texas Instruments, Dallas, TX, USA, pp. 1–12.
[2] Texas Instruments, LM358 Operational Amplifier Datasheet, Texas Instruments, Dallas, TX, USA, pp. 1–33.
[3] STMicroelectronics, 74LS86 Quad 2-Input Exclusive-OR Gate Datasheet, STMicroelectronics, Geneva, Switzerland, pp. 1–8.
[4] Handson Technology, L298N Motor Driver Module Datasheet, pp. 1–5. Available: https://www.handsontec.com/dataspecs/L298N%20Motor%20Driver.pdf, [Accessed: Jun. 25, 2026]
[5] GeeksforGeeks, "DC Motor – Working, Types and Applications," pp. 1–3. Available: https://www.geeksforgeeks.org/physics/dc-motor/, [Accessed: Jun. 25, 2026]
[6] D. A. Neamen, Microelectronics: Circuit Analysis and Design, 4th ed., McGraw-Hill, 2010, Chapter 9: Operational Amplifiers, pp. 621–668.
[7] C. K. Alexander and M. N. O. Sadiku, Fundamentals of Electric Circuits, 5th ed., McGraw-Hill, 2013, Chapter 5: Operational Amplifiers, pp. 175–213.
[8] A. V. Oppenheim, A. S. Willsky, and S. H. Nawab, Signals and Systems, 2nd ed., Prentice Hall, 1997, Chapter 3: RC Low-Pass Filter, pp. 239–241.
[9] Dassault Systèmes, "SOLIDWORKS 3D CAD Design Software." Available: https://www.solidworks.com/, [Accessed: Jun. 25, 2026]
[10] Vedantu, "Pulse Width Modulation (PWM) – Learn Important Terms and Concepts." Available: https://www.vedantu.com/physics/pulse-width-modulation, [Accessed: Jun. 25, 2026]
[11] Texas Instruments, 74LS74 D Flip Flop, Texas Instruments, Dallas, TX, USA, pp. 1–18.

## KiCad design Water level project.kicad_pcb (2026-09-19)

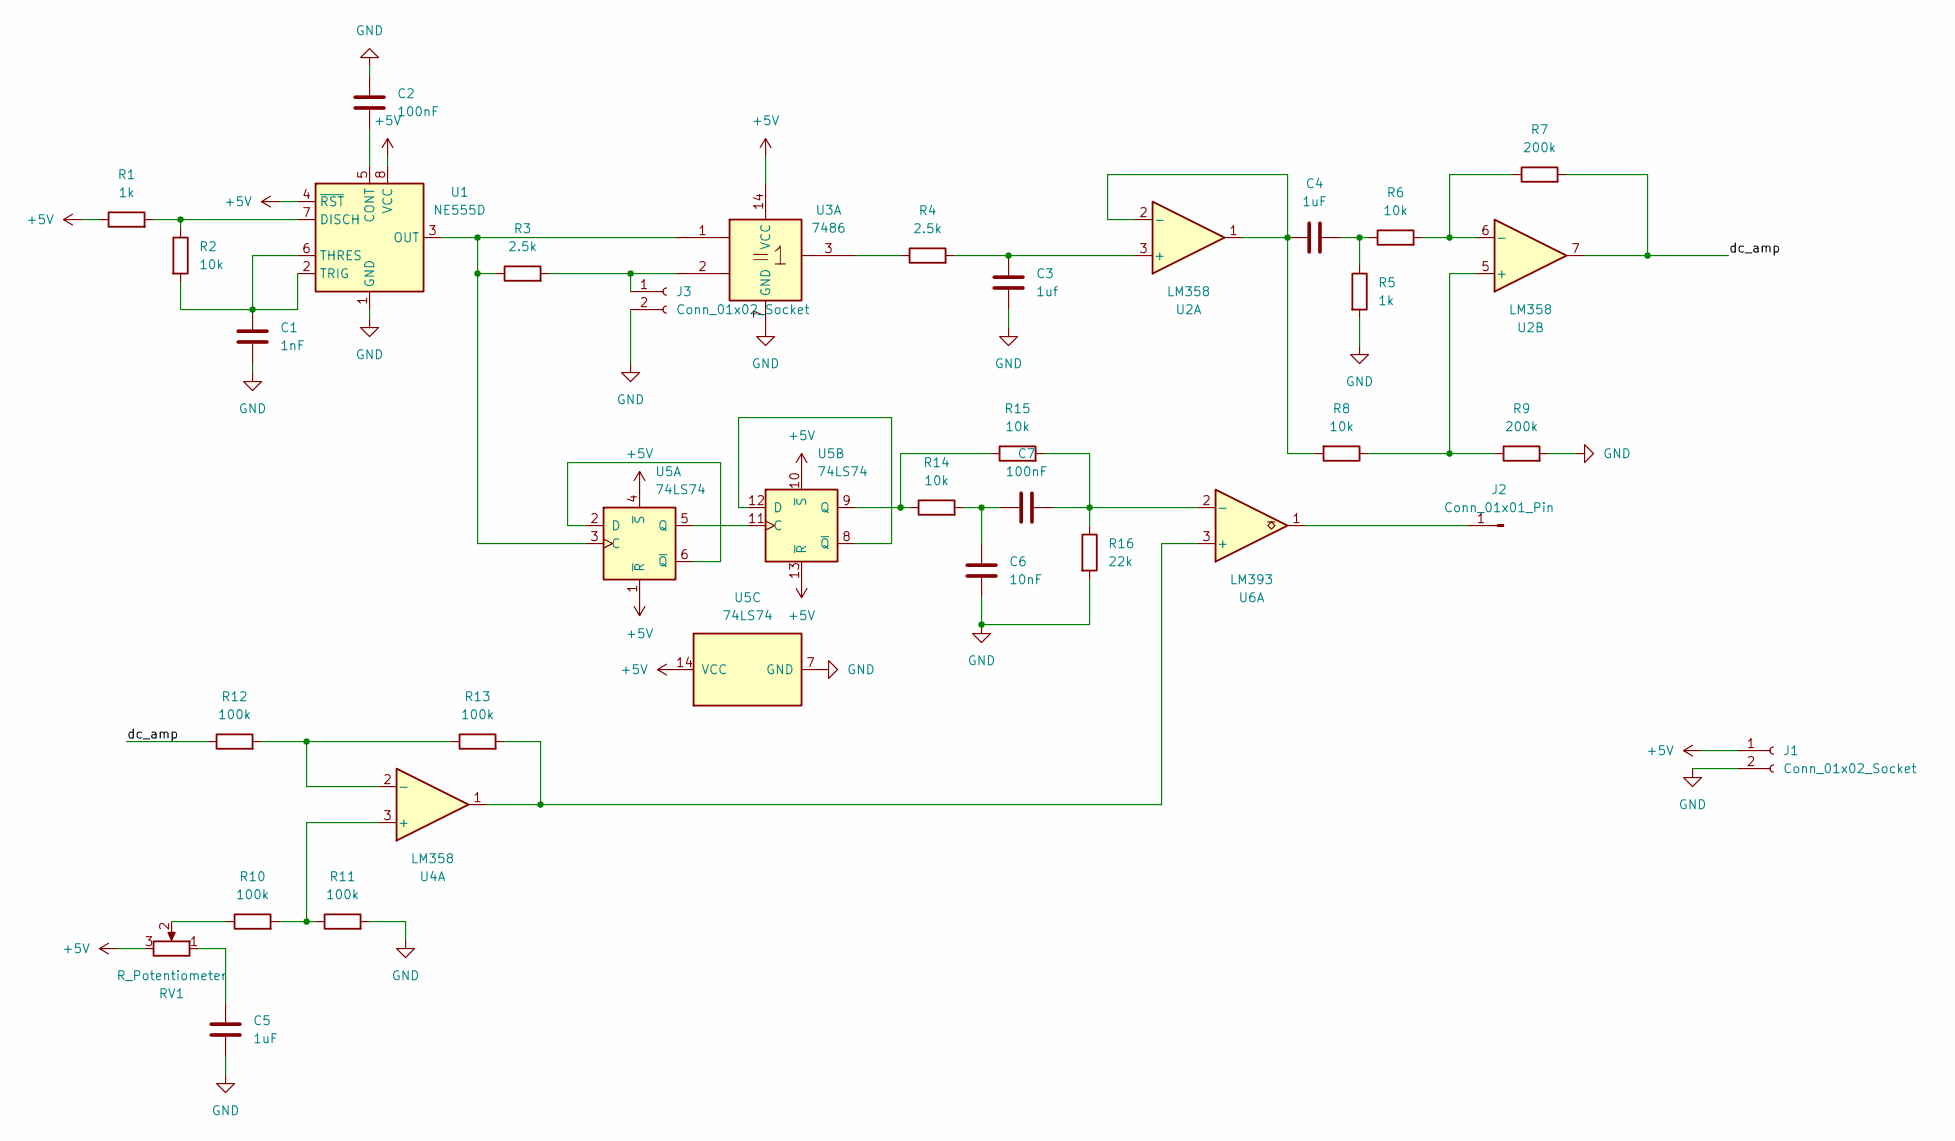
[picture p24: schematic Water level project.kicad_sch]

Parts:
C1: 1nF; C_Disc_D4.3mm_W1.9mm_P5.00mm
C2, C7: 100nF; C_Disc_D5.0mm_W2.5mm_P5.00mm
C3: 1uf; CP_Radial_D5.0mm_P2.50mm
C4, C5: 1uF; CP_Radial_D5.0mm_P2.50mm
C6: 10nF; C_Disc_D4.3mm_W1.9mm_P5.00mm
J1, J3: Conn_01x02_Socket; PinSocket_1x02_P2.54mm_Vertical
J2: Conn_01x01_Pin; PinSocket_1x01_P2.54mm_Vertical
R1, R5: 1k; R_Axial_DIN0207_L6.3mm_D2.5mm_P7.62mm_Horizontal
R2, R6, R8, R14, R15: 10k; R_Axial_DIN0207_L6.3mm_D2.5mm_P7.62mm_Horizontal
R3, R4: 2.5k; R_Axial_DIN0207_L6.3mm_D2.5mm_P7.62mm_Horizontal
R7, R9: 200k; R_Axial_DIN0207_L6.3mm_D2.5mm_P7.62mm_Horizontal
R10, R11, R12, R13: 100k; R_Axial_DIN0207_L6.3mm_D2.5mm_P7.62mm_Horizontal
R16: 22k; R_Axial_DIN0207_L6.3mm_D2.5mm_P7.62mm_Horizontal
RV1: R_Potentiometer; Potentiometer_Piher_PC-16_Single_Vertical
U1: NE555D; DIP-8_W7.62mm
U2, U4: LM358; DIP-8_W7.62mm
U3: 7486; DIP-14_W7.62mm
U5: 74LS74; DIP-14_W7.62mm
U6: LM393; DIP-8_W7.62mm

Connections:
+5V: J1.1, R1.1, RV1.3, U1.4 (~RST), U1.8 (VCC), U3.14 (VCC), U5.1 (~R), U5.4 (~S), U5.10 (~S), U5.13 (~R), U5.14 (VCC)
/dc_amp: R7.2, R12.1, U2.7
GND: C1.2, C2.1, C3.2, C5.2, C6.2, J1.2, J3.2, R5.2, R9.2, R11.2, R16.2, U1.1 (GND), U3.7 (GND), U5.7 (GND)
unnamed: C4.2, R5.1, R6.1
unnamed: C5.1, RV1.1
unnamed: C6.1, C7.1, R14.2
unnamed: J2.1 (Pin_1_1), U6.1
unnamed: J3.1, R3.2, U3.2
unnamed: R4.1, U3.3
unnamed: R10.1, RV1.2
unnamed: C2.2, U1.5 (CONT)
unnamed: R1.2, R2.1, U1.7 (DISCH)
unnamed: R3.1, U1.3 (OUT), U3.1, U5.3 (C)
unnamed: C1.1, R2.2, U1.2 (TRIG), U1.6 (THRES)
unnamed: C3.1, R4.2, U2.3 (+)
unnamed: C4.1, R8.2, U2.1, U2.2 (-)
unnamed: R8.1, R9.1, U2.5 (+)
unnamed: R6.2, R7.1, U2.6 (-)
unnamed: R10.2, R11.1, U4.3 (+)
unnamed: R12.2, R13.1, U4.2 (-)
unnamed: U5.2 (D), U5.6 (~Q)
unnamed: U5.5 (Q), U5.11 (C)
unnamed: U5.8 (~Q), U5.12 (D)
unnamed: R14.1, R15.1, U5.9 (Q)
unnamed: R13.2, U4.1, U6.3 (+)
unnamed: C7.2, R15.2, R16.1, U6.2 (-)

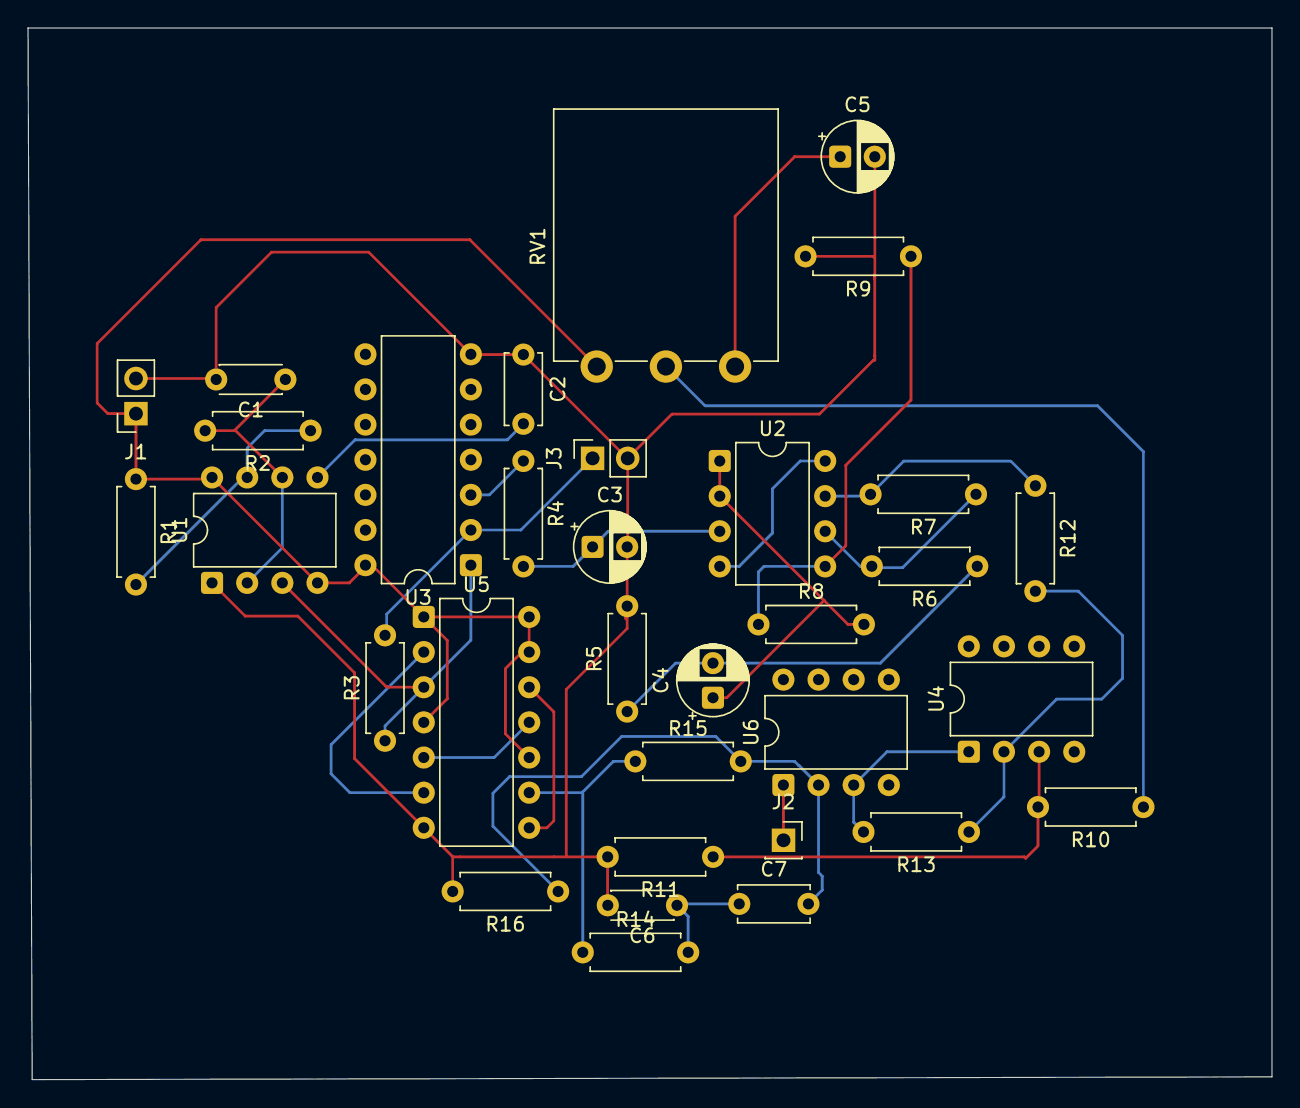
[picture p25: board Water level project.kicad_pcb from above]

Board: 2 copper layers, 89.9 x 76.0 mm, 33 parts (0 on the bottom side), 26 nets.

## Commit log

2026-09-19 Create PCB
2026-09-19 Create gerber file
2026-09-19 EE316 Water level project
    [Water level project.kicad_pcb, Water level project.kicad_sch]
